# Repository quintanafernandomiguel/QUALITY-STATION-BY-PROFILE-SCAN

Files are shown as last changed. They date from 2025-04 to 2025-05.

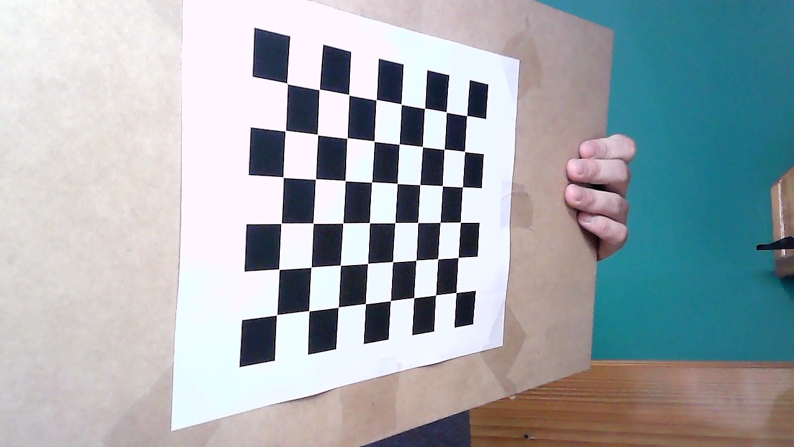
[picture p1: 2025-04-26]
Phyton/Calibracion/Imagenes/14.jpg

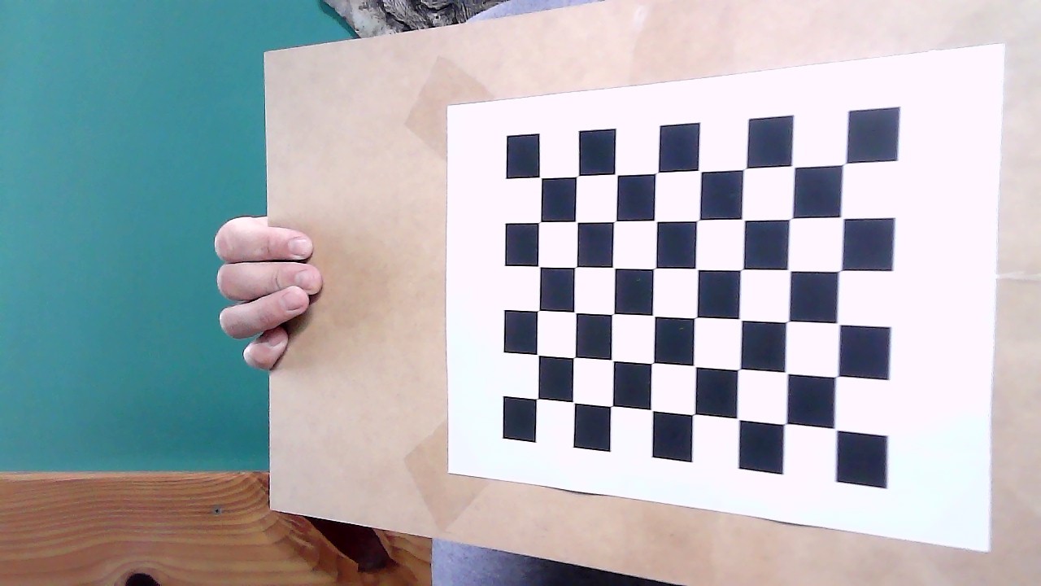
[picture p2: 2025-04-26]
Phyton/Calibracion/Imagenes/29.jpg

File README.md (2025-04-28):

# 📏 Quality Station by Profile Scan

LOGO AZUL HORIZONTAL - fondo transparente

**Universidad Nacional de Lomas de Zamora - Facultad de Ingeniería**  

**Carrera: Ingeniería Mecatrónica**

**Materia: Proyecto Final**

**Alumno: Quintana Fernando Miguel**

---

## 🎯 Motivación

En la industria moderna, donde la **velocidad, precisión y repetibilidad** son claves, el control de calidad sigue siendo una tarea muchas veces manual, lenta y propensa a errores humanos.

Este proyecto surge del interés por automatizar el control dimensional de piezas mediante **perfilometría óptica**. La propuesta plantea una alternativa accesible y didáctica a los perfilómetros industriales, utilizando una **cámara web, un láser de línea**, y técnicas de **procesamiento de imágenes con Python y OpenCV**.

---

## 🧠 Objetivo del Proyecto

Desarrollar una **estación de inspección automatizada**, capaz de:

- Escanear perfiles de piezas en tiempo real.
- Evaluar su conformidad dimensional.
- **Rechazar automáticamente** aquellas que no cumplen con las especificaciones.

---

## 🛠️ Componentes del Sistema

- **Cinta transportadora** motorizada controlada por Arduino.
- **Perfilómetro casero** (cámara web + láser de línea) para escaneo por triangulación.
- **Sensor láser** complementario para medición de distancia.
- **Controlador Arduino** que gestiona el sistema y toma decisiones.
- **Mecanismo de rechazo** activado por servoaccionamiento.
- **Interfaz gráfica en Jupyter Notebook** para visualizar estado, perfiles y resultados.

---

## ⚙️ Tecnologías Utilizadas

- **Python & OpenCV** – Procesamiento de imágenes y reconstrucción de perfiles.
- **Arduino** – Control de actuadores y adquisición de datos.
- **Jupyter Notebook** – Interfaz gráfica de usuario.
- **Diseño CAD** – Modelado mecánico de la estación.
- **Mecánica + Electrónica + Software** – Integración mecatrónica completa.

---

## 🔍 Alcance del Proyecto

Este sistema busca **automatizar el control de calidad** de piezas en una línea de producción, con un enfoque en:

- Diseño mecánico y estructura.
- Automatización con Arduino y control de motores/actuadores.
- Visión artificial aplicada, triangulación láser y escaneo.
- Desarrollo de software para análisis y visualización de resultados.

---

## 🚀 ¿Por qué es relevante?

- Aplica principios reales de la **industria 4.0**.
- Aporta una solución accesible al control dimensional automatizado.
- Ideal como proyecto didáctico, demostrativo y funcional.

---

## 📐 Esquemáticos del Sistema

PF - Quintana - Esquematico

PF - Quintana - Esquematico Comp

---

## 📸 Galería

> PF_Ensamblaje















---

## 🎥 Video de Funcionamiento

https://github.com/user-attachments/assets/4ed54965-bf86-45df-9e4f-574f1abf868d

https://github.com/user-attachments/assets/692bc483-f296-46c0-8a92-6665f114094d

https://github.com/user-attachments/assets/1b8ac1dd-ba24-4001-8854-6a46f08e3085

https://github.com/user-attachments/assets/44d58ee6-c109-4596-9ad5-b0a023ec7f68

https://github.com/user-attachments/assets/22328aee-efcb-4d32-8db1-715bef9cf719

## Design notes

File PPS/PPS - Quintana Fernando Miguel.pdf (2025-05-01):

# Informe de Práctica Profesional Supervisada

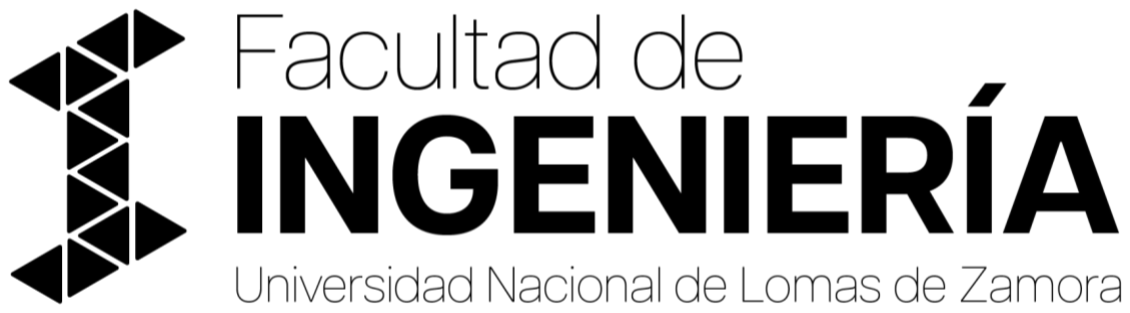
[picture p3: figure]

Institución: UNLZ-FI
Tutor Institucional: Lukaszewicz, Cristian
Tutor académico: Lukaszewicz, Cristian
Cargo institucional: Docente, materia: Proyecto final en ing. mecatrónica

Alumno: Quintana Fernando Miguel

_ _ _ _ _ _ _ _ _ _ _ _ _ _ _ _ _

Firma del Tutor Institucional

Índice

Reservado a la facultad para evaluación

Lugar donde he realizado la PPS

Desarrollé mi Práctica Profesional Supervisada en el laboratorio de Mecatrónica de la Universidad Nacional de Lomas de Zamora, Facultad de Ingeniería (UNLZ-FI), ubicado en Camino de Cintura, Avenida Juan XXIII, en la localidad de Lomas de Zamora, Provincia de Buenos Aires.

El laboratorio cuenta con diversas herramientas y tecnologías que facilitaron el desarrollo de mi proyecto, tales como fuentes de alimentación regulables, osciloscopios, multímetros y equipos de medición avanzada. Asimismo, dispone de un espacio de trabajo adecuado para el montaje, ensayo y validación de prototipos en las áreas de electrónica y mecatrónica.

Durante el transcurso de la práctica, recibí asesoramiento permanente por parte de los docentes Cristian Lukaszewicz, Ezequiel Blanca y Juan Szombach, quienes me brindaron orientación técnica y apoyo constante, permitiéndome avanzar de manera sólida en el desarrollo del proyecto.

Introducción

La automatización del control de calidad constituye uno de los pilares fundamentales de la industria moderna. El diseño de estaciones que integran técnicas de medición óptica, como la triangulación láser, junto con sistemas de visión artificial y automatización electromecánica, permite optimizar la productividad, garantizar la conformidad con los estándares de calidad y reducir significativamente los costos operativos.

En este contexto, desarrollé una estación de calidad automatizada que utiliza perfilometría basada en un láser de línea, una cámara web y programación en Python. La clasificación de las piezas inspeccionadas se gestionó mediante una placa Arduino, logrando así una solución eficiente, precisa y de bajo costo para la detección de defectos dimensionales en piezas en movimiento.

Objetivo

- Digitalizar en tiempo real el perfil superficial de las piezas inspeccionadas.
- Comparar los perfiles capturados con un modelo patrón previamente definido.
- Clasificar automáticamente las piezas como "OK" o "NO OK" mediante un sistema de rechazo controlado electrónicamente.

Principio de Triangulación Láser

La triangulación láser es una técnica de medición óptica sin contacto que permite determinar la posición tridimensional de un objeto mediante la proyección de un haz de luz y la detección de su reflexión desde un ángulo distinto.
El principio de funcionamiento se basa en que, al impactar el haz láser sobre la superficie de un objeto, el punto reflejado se registra en una posición diferente en el sensor óptico en función de la distancia al objeto. Conociendo la geometría del sistema (específicamente la distancia entre el láser y la cámara, y el ángulo de incidencia), es posible calcular la distancia precisa utilizando principios básicos de trigonometría.

Principales ventajas de la triangulación láser:

- Alta velocidad de adquisición de puntos, permitiendo capturas rápidas.
- Medición completamente sin contacto, ideal para superficies delicadas o en movimiento.
- Resolución adecuada para aplicaciones de inspección industrial y control de calidad.

La precisión del sistema depende directamente de diversos factores, tales como la calidad del haz láser, la sensibilidad y resolución del sensor óptico utilizado, así como la estabilidad mecánica de toda la configuración de medición.

Sensor CCD y su Rol en la Triangulación

Los sensores CCD (Charge Coupled Device) son componentes fundamentales en los sistemas de triangulación láser. Su funcionamiento se basa en la captura de la luz reflejada, que posteriormente es convertida en una señal eléctrica proporcional a la intensidad luminosa recibida.

Principales características del sensor CCD en aplicaciones de triangulación láser:

- Alta resolución espacial: permite capturar con precisión los detalles finos del perfil de las piezas inspeccionadas.
- Respuesta lineal: garantiza una correspondencia proporcional entre la intensidad luminosa detectada y la señal eléctrica generada.
- Sensibilidad espectral: posibilita la detección selectiva de la longitud de onda del láser mediante el uso de filtros ópticos específicos.

En los sistemas de triangulación, la cámara equipada con un sensor CCD detecta la deformación de la línea láser proyectada sobre el objeto, registrando su desplazamiento en la imagen. A partir de esta información, y aplicando los principios de triangulación geométrica, se calcula con precisión la distancia a cada punto del objeto medido.

Importancia del Punto Focal y Parámetros Ópticos

El punto focal es la región en la que el haz láser alcanza su máxima concentración de energía y su menor tamaño, generando un "spot" de alta precisión.
En los sistemas de triangulación láser, un spot reducido mejora significativamente la exactitud en la localización de los puntos de medición, mientras que una correcta focalización asegura una mayor nitidez en las imágenes capturadas por el sensor óptico.

Otros parámetros ópticos relevantes en la triangulación láser:

- Profundidad de Campo (DOF): define el rango de distancias dentro del cual el objeto permanece enfocado, siendo fundamental para capturar correctamente piezas de distintas alturas o geometrías variables.
- Campo de Visión (FOV): representa el área total observable por la cámara en cada captura, determinando el tamaño máximo del objeto que puede ser inspeccionado en una sola toma.
- Distancia de referencia (Standoff): es la distancia óptima entre el sensor y el objeto, donde se logra la mejor calidad de medición en términos de nitidez y precisión.
- Ángulo de Triangulación: es el ángulo formado entre el haz láser proyectado y la línea de visión de la cámara; afecta directamente tanto la precisión como el rango de medición disponible en el sistema.

La adecuada configuración de estos parámetros es esencial para maximizar el rendimiento de un sistema de medición basado en triangulación láser.

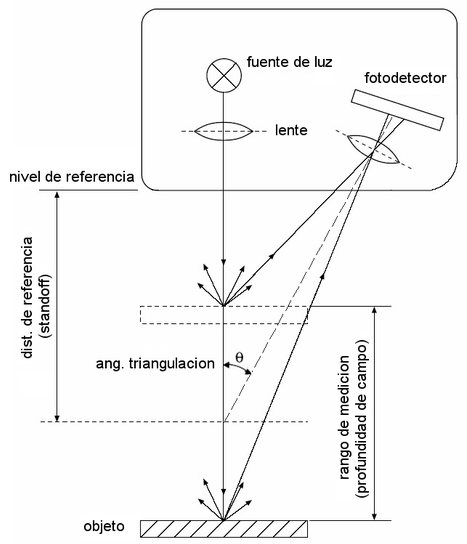
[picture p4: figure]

Descripción de la Estación de Calidad

El proyecto integra un sistema compuesto por un láser de línea, una cámara web utilizada como perfilómetro, y una cinta transportadora accionada por un motor paso a paso (PAP), todo controlado mediante una placa Arduino Nano.
La captura y el procesamiento de las imágenes del perfil de las piezas se realizan mediante programación en Python, utilizando la biblioteca OpenCV. El sistema identifica la proyección de la línea láser sobre la superficie de las piezas, detectando eventuales discrepancias al comparar el perfil capturado contra un modelo patrón predefinido. Cuando se detecta un perfil fuera de tolerancia, la placa Arduino acciona un servomotor encargado de desviar automáticamente la pieza defectuosa, asegurando la continuidad del flujo productivo sin intervención manual.
Adicionalmente, la estación cuenta con un sensor láser que mide de forma indirecta la longitud de las piezas transportadas. Esta medición se realiza mediante el conteo de los micropasos del motor paso a paso y su correlación con la distancia recorrida de la cinta transportadora.
Todo el proceso, desde la adquisición de datos hasta la clasificación de las piezas, es visualizado a través de una interfaz gráfica desarrollada en Jupyter Notebook, lo que permite un monitoreo continuo y detallado de la operación.

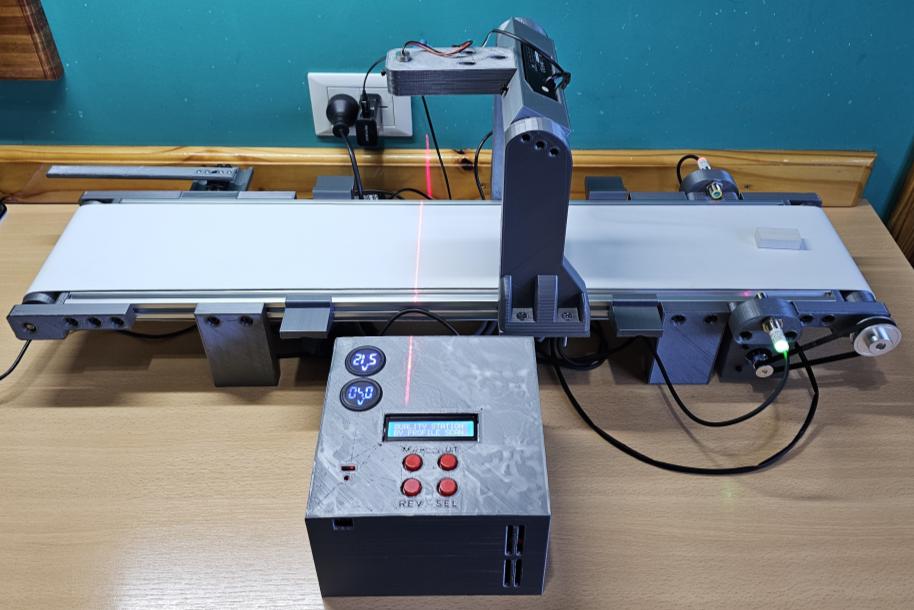
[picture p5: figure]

Metodología de Trabajo

El desarrollo de la estación de calidad automatizada se llevó a cabo siguiendo las siguientes etapas:

1. Calibración de la cámara: Realicé la obtención de la matriz intrínseca del sistema óptico y la corrección de las distorsiones de la lente, utilizando patrones de calibración y herramientas de visión computacional, asegurando así una captura precisa de las imágenes.

2. Configuración mecánica: Monté el láser de línea y la cámara web en soportes estables, estableciendo una distancia fija y un ángulo de triangulación adecuado para optimizar la detección del perfil proyectado sobre las piezas.
3. Programación en Arduino: Desarrollé el control de la cinta transportadora y del servomotor mediante una placa Arduino nano, permitiendo la gestión automática del desplazamiento de piezas y su clasificación en función del análisis de perfil.
4. Programación en Python: Implementé rutinas de captura de imágenes, procesamiento para la detección de la línea láser (utilizando filtrado de color y extracción de contornos) y algoritmos de comparación de perfiles para decidir el estado ("OK" o "NO OK") de cada pieza inspeccionada.
5. Validación mediante ensayos: Realicé pruebas experimentales con distintas piezas estándar para validar la precisión del sistema, calibrar tolerancias y ajustar los parámetros de funcionamiento, logrando optimizar la velocidad y fiabilidad del proceso de inspección.

Resultados Obtenidos

A partir de las pruebas experimentales realizadas, he obtenido los siguientes resultados:

- Detección precisa de perfiles activación automática del mecanismo de rechazo para las piezas fuera de tolerancia.
- Tiempos de inspección optimizados, logrando analizar y clasificar cada pieza en menos de 2 segundos, lo que permite un flujo continuo y eficiente en la línea de producción.
- Alta repetibilidad de los resultados en condiciones controladas de iluminación, asegurando estabilidad y confiabilidad en la detección de perfiles correctos.
- Precisión estimada de ±1 mm en la comparación de perfiles respecto al modelo patrón, suficiente para aplicaciones de inspección dimensional básica en entornos industriales o educativos.

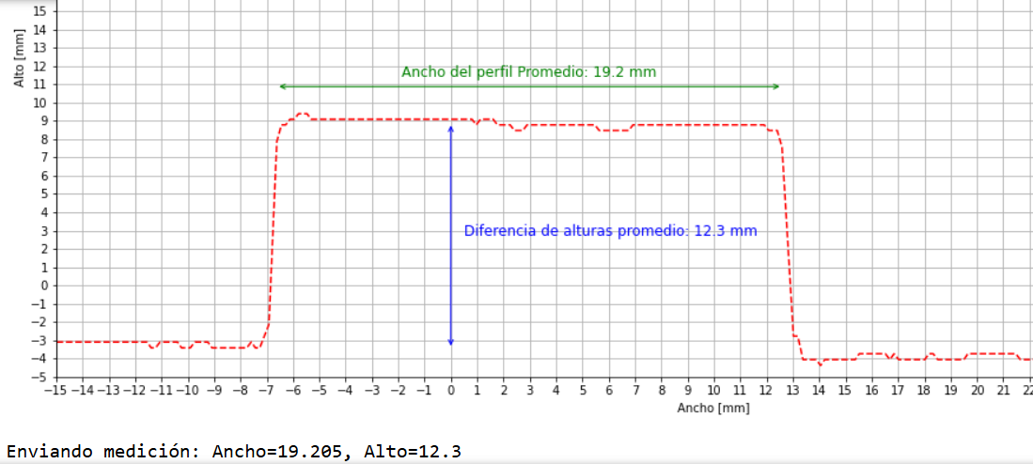
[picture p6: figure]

Ventajas y Limitaciones del Sistema

Ventajas:
- Bajo costo de materiales y desarrollo.
- Flexibilidad para modificar criterios de aceptación.
- Automatización total del proceso de inspección.

Limitaciones:
- Sensibilidad a condiciones de luz externa.
- Requiere calibración periódica.
- Dependencia de la calidad óptica de la webcam.

Costos

A continuación, muestro los diferentes elementos que componen al proyecto junto con su costo de adquisición. Esos costos extra rondan los 443,94 USD.

CANTIDAD DESCRIPCIÓN PRECIO POR UNIDAD IMPORTE $ | IMPORTE USD
1 Adaptador paralelo serie I2c $ 2.970,00 $ 2.970,00 | USD 2,27
1 Arduino Nano Atmega328 CH340 $ 5.800,00 $ 5.800,00 | USD 4,43
1 Banda R#9 130 mm x 1620 mm (ROLMEC PU-R9AM-135) $ 198.137,00 $ 198.137,00 | USD 151,25
1 Bornera enchufable hembra 3 vias P:5,08 $ 1.850,00 $ 1.850,00 | USD 1,41
2 Bornera enchufable hembra 8 vias P:5,08 $ 1.962,00 $ 3.924,00 | USD 3,00
1 Bornera enchufable macho 3 vias P:5,08 $ 1.250,00 $ 1.250,00 | USD 0,95
2 Bornera enchufable macho 8 vias P:5,08 $ 1.360,00 $ 2.720,00 | USD 2,08
4 Boton momentaneo B3f 4055 $ 480,00 $ 1.920,00 | USD 1,47
1 Cable 1 metro Nema 17 $ 2.861,00 $ 2.861,00 | USD 2,18
1 Camara REDRAGON FOBOS GW600-1 $ 59.000,00 $ 59.000,00 | USD 45,04
6 Conector terminal PCB 3x1 3,5mm $ 3.054,50 $ 18.327,00 | USD 13,99
1 Correa cerrada 280 mm GT2 6 mm 140 dientes $ 4.626,00 $ 4.626,00 | USD 3,53
1 Display LCD 16x2 HD44780 $ 7.620,00 $ 7.620,00 | USD 5,82
1 Driver TB6600 $ 14.950,00 $ 14.950,00 | USD 11,41
1 Fan cooler 3007 30 mm 5V $ 6.862,00 $ 6.862,00 | USD 5,24
2 Filamento PLA 1,75 Grilon3 1kg $ 19.569,00 $ 39.138,00 | USD 29,88
30 Inserto M3 impresión 3D $ 340,66 $ 10.219,80 | USD 7,80
1 Laser de linea 5 VDC 650 nm $ 8.825,00 $ 8.825,00 | USD 6,74
1 Modulo Asilamiento Optoacoplador Pc817 $ 5.979,00 $ 5.979,00 | USD 4,56
1 Modulo Stepdown XI4016 36V 8a $ 9.296,00 $ 9.296,00 | USD 7,10
1 Nema 17 1.8° / 42ncm $ 19.900,00 $ 19.900,00 | USD 15,19
1 PCB experimental 3x7 $ 3.343,00 $ 3.343,00 | USD 2,55
1 PCB experimental 4X6 $ 3.420,00 $ 3.420,00 | USD 2,61
2 Perfil Bosch Tslot 2020 1 metro $ 10.826,00 $ 21.652,00 | USD 16,53
1 Polea GT2 20 dientes, correa 6 mm, 5 mm aluminio $ 2.980,00 $ 2.980,00 | USD 2,27
1 Polea GT2 60 dientes, correa 6 mm, 8 mm aluminio $ 9.775,00 $ 9.775,00 | USD 7,46
4 Resitencia 10Kohm $ 45,00 $ 180,00 | USD 0,14
4 Rodamiento 608 ZZ $ 1.406,50 $ 5.626,00 | USD 4,29
1 Sensor Laser CLOWEIT J12-T20P2 $ 42.500,00 $ 42.500,00 | USD 32,44
1 Servo MG996r 10Kg Torque $ 11.600,00 $ 11.600,00 | USD 8,85
40 Tornillos allen M5 x 12 mm $ 299,05 $ 11.962,00 | USD 9,13
50 Turcas martillo perfil 2020 M5 $ 380,00 $ 19.000,00 | USD 14,50
1 Varilla templada y rectificada 8 mm x 425 mm $ 8.344,00 $ 8.344,00 | USD 6,37
2 Voltimetro digital 30 mm 4V a 100V (azul) $ 7.500,00 $ 15.000,00 | USD 11,45
TOTAL | $ 581.556,80 | USD 443,94

Conclusiones

Durante la realización de la Práctica Profesional Supervisada, he implementado con éxito una estación de control de calidad automatizada basada en el principio de triangulación láser, utilizando tecnologías accesibles como Arduino Nano, motores paso a paso, sensores ópticos y programación en Python.
Logré diseñar e integrar un sistema funcional capaz de capturar, analizar y clasificar perfiles de piezas en movimiento, replicando las funcionalidades de estaciones industriales de mayor complejidad y costo.

El proyecto integró la captura de imágenes del perfil superficial de las piezas mediante una cámara web, el procesamiento en tiempo real utilizando la biblioteca OpenCV y la comparación de los perfiles capturados contra un modelo patrón predefinido.
La detección de discrepancias activó un servomecanismo que permitió desviar automáticamente las piezas fuera de tolerancia, garantizando la continuidad del flujo de producción sin necesidad de intervención humana.

Además, incorporé un sensor láser complementario que realizó mediciones indirectas de la longitud de las piezas, sincronizando la información con el conteo de micropasos del motor paso a paso que accionó la cinta transportadora. Esta integración de hardware y software permitió realizar un doble control dimensional de forma simultánea: perfil superficial y longitud longitudinal.

Implementé una interfaz gráfica en Jupyter Notebook que permitió el monitoreo visual en tiempo real del proceso, facilitando la supervisión de perfiles, estados de piezas y estadísticas de producción.

A través de numerosas pruebas experimentales, calibré los parámetros críticos del sistema, optimizando la distancia entre el láser y la cámara, ajustando la sensibilidad del sensor óptico, y sincronizando el desplazamiento de la cinta con el control de rechazo. Conseguí tiempos de inspección inferiores a dos segundos por pieza, manteniendo una precisión adecuada para aplicaciones prototipo y de nivel preindustrial.

Esta experiencia me permitió consolidar competencias clave en metrología óptica, visión artificial, programación embebida, control de motores y diseño de sistemas automatizados.
He fortalecido mi capacidad para integrar distintas tecnologías en soluciones prácticas, enfrentando desafíos técnicos reales y desarrollando habilidades interdisciplinarias esenciales para mi futura actividad profesional.
Considero que esta práctica no solo me brindó una formación técnica avanzada, sino que también sentó las bases para futuras mejoras, como la incorporación de escaneo tridimensional completo y la aplicación de técnicas de aprendizaje automático para la optimización del proceso de clasificación.

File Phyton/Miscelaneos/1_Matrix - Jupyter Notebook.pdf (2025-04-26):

# Universidad Nacional de Lomas de Zamora

## Facultad de Ingeniería

### Proyecto FINAL - Estacion de calidad por Perfilómetria

Alumno: QUINTANA, Fernando Miguel

26/4/25, 14:56 | 1_Matrix - Jupyter Notebook
localhost:8891/notebooks/GitHub/Phyton/Programa/Codigos/1_Matrix.ipynb | 1/9

localhost:8891/notebooks/GitHub/Phyton/Programa/Codigos/1_Matrix.ipynb | 2/9

In [ ]: import numpy as np

# GeometrySpace

# Planos y rectas en el espacio euclídeo 3D

# https://www2.eii.uva.es/fund_inf/python/notebooks/Bibliotecas/03_Numpy/Numpy.html

def normaliza(v, tol=1e-6):
"""
Devuelve el vector normalizado de v.

Parameters
v : list, tuple, numpy.ndarray: numérico
Vector unidimensional
tol : float
Tolerancia que debe cumplir la norma del vector v Returns
v_norm : numpy.ndarray of floats
Vector normalizado unitario Raises
ValueError
Si la norma del vector inicial es inferior a tol Example
>>> v = (1, 1, 1)
>>> normaliza(v)
"""

norma = np.linalg.norm(v)
if norma < tol:
raise ValueError("La norma del vector es inferior a la tolerancia {}.".format(tol)) v_norm = v / norma # Al usar np.linalg.norm() v_norm es un numpy.ndarray
return v_norm

def distancia_entre_puntos(p1, p2):

localhost:8891/notebooks/GitHub/Phyton/Programa/Codigos/1_Matrix.ipynb | 3/9

"""
Calcula la distancia entre dos puntos en el espacio.

Parameters
p1, p2 : numpy.ndarray
Vectores unidimensionales
Returns
dist : numpy.float
Distancia entre los puntos p1 y p2 Example:
>>> p1 = np.array((1, 1, 1), dtype=float) >>> p2 = np.array((2, 3, 4), dtype=float)
>>> distancia_entre_puntos(p1, p2)
"""
dist = np.linalg.norm(p1 - p2) # p1-p2 no está definido para tuplas o listas return dist

def angulo(v1, v2):
"""
Calcula el ángulo en radianes entre dos vectores.

Parameters
v1, v2 : tuple, list, numpy.ndarray: numérico Vectores unidimensionales
Returns
angulo : float
Ángulo en radianes que forman los vectores Example
>>> u_x = [1, 0, 0] # Vector unitario eje X
>>> u_y = [0, 1, 0] # Vector unitario eje Y
>>> angulo(u_x, u_y)*180/np.pi # Ángulo en grados """

prod_esc = np.dot(v1, v2)
norma_v1 = np.linalg.norm(v1)
localhost:8891/notebooks/GitHub/Phyton/Programa/Codigos/1_Matrix.ipynb | 4/9

norma_v2 = np.linalg.norm(v2)

angulo = np.arccos(np.clip(prod_esc / (norma_v1 * norma_v2), -1, 1)) return angulo

def plano_tres_puntos(p1, p2, p3, tol=1e-3):
"""
Calcula el plano definido por tres puntos en el espacio.

Parameters
p1, p2, p3 : numpy.ndarray of floats
Vectores unidimensionales representando 3 puntos 3D
tol : float
Tolerancia que deben cumplir las distancias entre los puntos Returns
n, D : tuple : (numpy.ndarray of float, numpy float)
n es el vector unitario perpendicular al plano
D es el término independiente de la ecuación algebraica Ax+By+Cz+D=0 Raises
ValueError
Si la distancia entre alguno de los 3 puntos es inferior a tol Example
>>> p1 = np.array((1, 0, 0))
>>> p2 = np.array((0, 1, 0))
>>> p3 = np.array((0, 0, 1))
>>> n, D = plano_tres_puntos(p1, p2, p3) """
dist12 = distancia_entre_puntos(p1, p2)
dist13 = distancia_entre_puntos(p1, p3)
dist23 = distancia_entre_puntos(p2, p3)

if dist12 < tol or dist13 < tol or dist23 < tol:
raise ValueError("Distancia entre puntos menor que la tolerancia {}.".format(tol))

# Producto vectorial para A B C

# | i | j | k | |

# |v_12[0] v_12[1] v_12[2]|

localhost:8891/notebooks/GitHub/Phyton/Programa/Codigos/1_Matrix.ipynb | 5/9

# |v_13[0] v_13[1] v_13[2]|

v12 = p1 - p2
v13 = p1 - p3

n = normaliza(np.cross(v12, v13))

D = -np.dot(n, p1)

return n, D

def recta_dos_puntos(p1, p2, tol=1e-3): """
Parameters
p1, p2 : numpy.ndarray of floats
Vectores unidimensionales representando 2 puntos 3D
tol : float
Tolerancia que debe cumplir la distancia entre los puntos Returns
p, v : tuple: (numpy.ndarray of float, numpy.ndarray of float) p es una copia de p1, punto pasado como primer parámetro

v es el vector director unitario de la recta
Raises
ValueError
Si la distancia entre los 2 puntos es inferior a tol Example
>>> p1 = np.array((2, 2, 2))
>>> p2 = np.array((3, 3, 3))
>>> p, v = recta_dos_puntos(p1, p2)
"""
if distancia_entre_puntos(p1, p2) < tol:
raise ValueError("Distancia entre puntos menor que la tolerancia {}.".format(tol)) v = normaliza(p1 - p2)
return np.copy(p1), v
localhost:8891/notebooks/GitHub/Phyton/Programa/Codigos/1_Matrix.ipynb | 6/9

def interseccion_recta_plano(recta, plano, tol=0.0005): """
Parameters
recta : tuple : (numpy.ndarray of floats, numpy.ndarray of floats) Recta definida por la tupla punto inicial y vector director
p=p_0+l*v
plano : tuple : (numpy.ndarray of floats, float)
Plano definido por la tupla vector normal (A, B, C) y término independiente D Ax+By+Cz+D=0
tol : float
Tolerancia que deben cumplir el ángulo entre recta y plano
Returns
p : numpy.ndarray of floats
El punto de intersección
Raises
ValueError
Si el ángulo entre ambas figuras es inferior a tol en radianes Example
>>> p1 = np.array((1, 0, 0))
>>> p2 = np.array((0, 1, 0)) >>> p3 = np.array((0, 0, 1))
>>> p4 = np.array((2, 2, 2))
>>> p5 = np.array((3, 3, 3))
>>> plano = plano_tres_puntos(p1, p2, p3) >>> recta = recta_dos_puntos(p4, p5)
>>> p = interseccion_recta_plano(recta, plano) """
ang = angulo(recta[1], plano[0])

if np.abs(ang - np.pi / 2) < tol:
print(np.abs(ang - np.pi / 2))
raise ValueError("La recta y el plano son casi paralelos según tolerancia {}.".format(tol))

lamb = -(np.dot(recta[0], plano[0]) + plano[1]) / np.dot(recta[1], plano[0])

return recta[0] + lamb * recta[1]

localhost:8891/notebooks/GitHub/Phyton/Programa/Codigos/1_Matrix.ipynb | 7/9

# --------------------------------------# GeneradorMatriz

# punto focal

p_focal = np.array((-96.10, 166.45, 0))

# punto plano del laser

p_laser_1 = np.array((0, 0, 0)) p_laser_2 = np.array((0, 1, 0))
p_laser_3 = np.array((0, 0, 1))

# Datos cámara

px_wh = 0.003 # mm tamaño de alto - ancho de cada pixel
focal_dist = 7.8 # mm distancia focal de cámara
W = 732 | # Referencia pixeles verticales -> range(0, 733):
H = 1296 | # Referencia pixeles horizontales -> range(-648, 649):

# Creamos el plano del láser

plano_laser = plano_tres_puntos(p1=p_laser_1, p2=p_laser_2, p3=p_laser_3)

# Recorremos cada pixel del sensor de la cámara

mtx_ppx = []
mtx_ppy = []
mtx_ppz = []

for fpx in range(0, 733):
aux_x = []
aux_y = []
aux_z = []

# Posición de cada pixel en X e Y (varía con la fila)

pos_x = fpx * px_wh * np.cos(30 * np.pi / 180) - (100 + 360 * px_wh * np.cos(30 * np.pi / 180)) pos_y = fpx * px_wh * np.sin(30 * np.pi / 180) + (173.21 - 360 * px_wh * np.sin(30 * np.pi / 180))

# Recorremos por columna del sensor

for cpx in range(-648, 649):
if cpx == 0:
pass
else:
pos_z = cpx * px_wh
localhost:8891/notebooks/GitHub/Phyton/Programa/Codigos/1_Matrix.ipynb | 8/9

In [ ]:

# Creamos la recta del laser

px_pos = np.array((pos_x, pos_y, pos_z))
recta_haz = recta_dos_puntos(px_pos, p_focal)

# Obtenemos intersección recta-plano

intersection = interseccion_recta_plano(recta=recta_haz, plano=plano_laser)

# Guardamos la posición X,Y,Z en el espacio para ese pixel

XX = np.around(intersection, 3).tolist()[0]
YY = np.around(intersection, 3).tolist()[1]
ZZ = np.around(intersection, 3).tolist()[2]

#print(px_pos)

print("Para el pixel en el punto " + str(px_pos) + " --- > " + str(XX) + ";" + str(YY) + ";" + str(ZZ) aux_x.append(XX)
aux_y.append(YY)
aux_z.append(ZZ)

mtx_ppx.append(aux_x)
mtx_ppy.append(aux_y)
mtx_ppz.append(aux_z)

np.savetxt("mtx_x_izq.txt", mtx_ppx) np.savetxt("mtx_y_izq.txt", mtx_ppy) np.savetxt("mtx_z_izq.txt", mtx_ppz)

localhost:8891/notebooks/GitHub/Phyton/Programa/Codigos/1_Matrix.ipynb | 9/9

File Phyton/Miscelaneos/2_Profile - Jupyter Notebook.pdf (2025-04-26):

# Universidad Nacional de Lomas de Zamora

## Facultad de Ingeniería

### Proyecto FINAL - Estacion de calidad por Perfilómetria

Alumno: QUINTANA, Fernando Miguel | ¶
26/4/25, 14:56 | 2_Profile - Jupyter Notebook
localhost:8891/notebooks/GitHub/Phyton/Programa/Codigos/2_Profile.ipynb | 1/19

localhost:8891/notebooks/GitHub/Phyton/Programa/Codigos/2_Profile.ipynb | 2/19

In [ ]: # --------------------------------# Importamos librerías
import numpy as np
import cv2
import matplotlib.pyplot as plt

# Cargamos los archivos de las matrices de posición X, Y y Z mtx_xi = np.loadtxt("mtx_x_izq.txt") # Matriz pos. pixeles en X

mtx_yi = np.loadtxt("mtx_y_izq.txt") # Matriz pos. pixeles en Y
mtx_zi = np.loadtxt("mtx_z_izq.txt") # Matriz pos. pixeles en Z

# Creamos las variables auxiliares a utilizar en la ejecución del programa

scale_factor_x = 1 | # Escalado en X
scale_factor_y = 2.3 | # Escalado en Y
scale_factor_z = 2.3 | # Escalado en Z

# Creamos los offset en X, Y y Z para mover el grafico. offset_x = 0

offset_y = -18
offset_z = 0

# Creamos la función para filtrado de "ROJO" mediante HSV def HSV_FILTRO(image):

# Duplicamos la imagen

result = image.copy()
# Convertimos la imagen a espacio de color HSV

hsv_image = cv2.cvtColor(image, cv2.COLOR_BGR2HSV)
# Definimos los límites inferiores y superiores del color rojo en HSV lower_red = np.array([0, 50, 50])

upper_red = np.array([10, 255, 255])
# Creamos la máscara para el color rojo

mask1 = cv2.inRange(hsv_image, lower_red, upper_red)
# Definimos un rango adicional para el color rojo debido a su disposición en el espacio de color HSV lower_red = np.array([170, 50, 50])

upper_red = np.array([180, 255, 255])
# Creamos otra máscara para el color rojo

mask2 = cv2.inRange(hsv_image, lower_red, upper_red)
# Combinamos ambas máscaras para obtener una única máscara para el rojo

mask = cv2.bitwise_or(mask1, mask2)
# Aplicamos la máscara a la imagen original para obtener solo los píxeles rojos

localhost:8891/notebooks/GitHub/Phyton/Programa/Codigos/2_Profile.ipynb | 3/19

result = cv2.bitwise_and(result, result, mask=mask) # Convertimos la imagen resultante a escala de grises img_gris = cv2.cvtColor(result, cv2.COLOR_BGR2GRAY) # Retornamos la imagen filtrada
return img_gris

# Creamos la función para calibración de imagen

def CALIBRAR(imagen, h, w):
# PROPIEDADES INTRÍNSECAS DE CÁMARA

# Matriz intrínseca de Cámara

M_int = np.array([[1.38106997e03, 0.00000000e00, 6.87317037e02], [0.00000000e00, 1.38209804e03, 3.82421364e02], [0.00000000e00, 0.00000000e00, 1.00000000e00]])

# Matríz de Distorsión

D = np.array([8.30863128e-02, 1.57413825e00, 4.52467136e-04, 5.90615097e-03, -7.07611874e00])

# Matriz Transformación de Cámara - Pixel

newcameramtx, roi = cv2.getOptimalNewCameraMatrix(M_int, D, (w, h), 1, (w, h), centerPrincipalPoint=False)

# Matriz Imagen calibrada

dst = cv2.undistort(imagen, M_int, D, None, newcameramtx)

# Se ajusta tamaño de imagen

x, y, w, h = roi
dst = dst[y : y + h, x : x + w]

# Retorna imagen calibrada

return dst

# Creamos la función para procesar la imagen

def PROCESAR(image):
# Inicializamos las variables a utilizar

perfil_puntos = [] # Lista de puntos del perfil de la pieza
pos_pix2 = [] # Lista de cada pixel a encontrar en las matrices de referencia

# Obtenemos el tamaño de la imagen recibida

h, w = image.shape[:2]

# Procesamos la imagen -> calibramos y filtramos "ROJO" image = CALIBRAR(image, h, w)

image = HSV_FILTRO(image)
localhost:8891/notebooks/GitHub/Phyton/Programa/Codigos/2_Profile.ipynb | 4/19

# Aplicamos un tresh para poner los pixeles en 1 o 0 según los valores límites fijados image = cv2.threshold(image, 15, 255, cv2.THRESH_BINARY)[1]

# Mostramos imagen con umbral aplicado

cv2.imshow("Imagen", image)
cv2.waitKey(0)

# Recorremos todas las columnas de la imagen, para asegurarnos obtener una linea lo más fina posible a la curv img_columnas = len(image[0]) # Obtenemos la cantidad de columnas que tiene la imagen

for col in range(0, img_columnas):
vpx = np.where(image[:, col] != 0) # Aquellos pixeles con "1" son los pixeles que queremos ubicar

# Si para dicha columna tenemos pixeles en "1", entonces lo guardamos en la lista

if len(vpx[0]) > 0:
# Ubicamos el pixel más centrado de la linea para ajustar lo más posible.

if len(vpx[0]) % 2 == 0:
pos_pix2.append([vpx[0][int(len(vpx[0]) / 2)], col])
else:
pos_pix2.append([vpx[0][int(round(len(vpx[0]) / 2, 0))], col])

# Para cada posición encontrada, se obtienen los valores de X, Y y Z en el espacio según sistema de referencia for px in pos_pix2:

# Posición en X * escalado

x = (mtx_xi[px[0], px[1]] * scale_factor_x) + offset_x
# Posición en Y * escalado

y = (mtx_yi[px[0], px[1]] * scale_factor_y) + offset_y
# Posición en Z * escalado

z = (mtx_zi[px[0], px[1]] * scale_factor_z) + offset_z

# Guardamos en la lista la posición en X, Y y Z de cada pixel perfil_puntos.append([x, y, z])

# Retornamos la lista de puntos

return np.array(perfil_puntos)

# Leemos imagen del directorio

img = cv2.imread("D:/Trabajo Final (Perfilometro)/Programa/ImgsPerfilometro/WIN_20240208_21_51_56_Pro.jpg") #img = cv2.imread("D:/Trabajo Final (Perfilometro)/Programa/ImgsPerfilometro/WIN_20240218_16_16_26_Pro.jpg")

# Mostramos imagen original

localhost:8891/notebooks/GitHub/Phyton/Programa/Codigos/2_Profile.ipynb | 5/19

cv2.imshow("Original", img) cv2.waitKey(0)

# Procesamos imagen y obtenemos el perfil

puntos_perfil = PROCESAR(img)

# Graficamos los puntos obtenidos

plt.figure(figsize=(20, 10)) # Ajustamos el tamaño del gráfico plt.plot(puntos_perfil[:, 2], puntos_perfil[:, 1], linestyle="dashed", color="red") plt.xticks(range(-15, 35, 1)) # Ajustamos los intervalos de los números en los ejes x y y plt.yticks(range(-5, 30, 1))
plt.grid()
plt.xlabel("Ancho [mm]")
plt.ylabel("Alto [mm]")
plt.xlim(-15, 35)
plt.ylim(-5, 30)
plt.show()
localhost:8891/notebooks/GitHub/Phyton/Programa/Codigos/2_Profile.ipynb | 6/19

### Calculo de altura del perfil

localhost:8891/notebooks/GitHub/Phyton/Programa/Codigos/2_Profile.ipynb | 7/19

In [ ]: | # Calculamos la altura puntos_encima_2mm = puntos_perfil[puntos_perfil[:, 1] > 2] # Filtramos los puntos por encima de 2 mm en el eje Y puntos_debajo_2mm = puntos_perfil[puntos_perfil[:, 1] < 2] # Filtramos los puntos por debajo de 2 mm en el eje Y
| # Ordenamos los puntos filtrados por su valor en el eje X puntos_encima_2mm_sorted = np.sort(puntos_encima_2mm, axis=0) puntos_debajo_2mm_sorted = np.sort(puntos_debajo_2mm, axis=0)
| # Calculamos los índices que representan el 10% de los valores más bajos y altos para los puntos por encima de 2 m n_encima = len(puntos_encima_2mm_sorted) low_index_encima = int(n_encima * 0.1) high_index_encima = int(n_encima * 0.9)
| # Seleccionamos solo los valores dentro del rango del 10% al 90% para los puntos por encima de 2 mm puntos_80_percent_encima = puntos_encima_2mm_sorted[low_index_encima:high_index_encima]
| # Calculamos el promedio de los valores seleccionados para los puntos por encima de 2 mm altura_promedio_80_percent_encima = np.mean(puntos_80_percent_encima[:, 1])
| # Realizamos el mismo proceso para los puntos por debajo de 2 mm n_debajo = len(puntos_debajo_2mm_sorted) low_index_debajo = int(n_debajo * 0.1) high_index_debajo = int(n_debajo * 0.9) puntos_80_percent_debajo = puntos_debajo_2mm_sorted[low_index_debajo:high_index_debajo] altura_promedio_80_percent_debajo = np.mean(puntos_80_percent_debajo[:, 1])
| # Calculamos la diferencia entre los promedios de los puntos por encima y por debajo de 2 mm diferencia_altura_promedio = round(altura_promedio_80_percent_encima - altura_promedio_80_percent_debajo, 1)
| # Mostramos los resultados print("Altura promedio del perfil (80% de los valores por encima de 2 mm):", round(altura_promedio_80_percent_enci print("Altura promedio de la base (80% de los valores por debajo de 2 mm):", round(altura_promedio_80_percent_deba print("Diferencia de alturas promedio:", diferencia_altura_promedio, "mm")
localhost:8891/notebooks/GitHub/Phyton/Programa/Codigos/2_Profile.ipynb | 8/19

### Calculo del ancho del perfil

In [ ]: | # Encontrar el inicio y el final del perfil inicio_perfil = None fin_perfil = None for i in range(len(puntos_perfil)): # Si el valor de Y es mayor a 2 mm, encontramos el inicio del perfil if puntos_perfil[i, 1] > 2: inicio_perfil = i break
| for i in range(len(puntos_perfil) - 1, -1, -1): # Si el valor de Y es mayor a 2 mm, encontramos el final del perfil if puntos_perfil[i, 1] > 2: fin_perfil = i break
| # Calcular el ancho del perfil if inicio_perfil is not None and fin_perfil is not None: ancho_perfil = puntos_perfil[inicio_perfil, 2] - puntos_perfil[fin_perfil, 2] print("Ancho del perfil:", ancho_perfil, "mm") else: print("No se encontraron puntos para calcular el ancho del perfil.")
localhost:8891/notebooks/GitHub/Phyton/Programa/Codigos/2_Profile.ipynb | 9/19

### Graficamos el perfil con los datos obtenidos

In [ ]: | # Graficar el perfil con datos: plt.figure(figsize=(20, 10)) # Ajustamos el tamaño del gráfico plt.plot(puntos_perfil[:, 2], puntos_perfil[:, 1], linestyle="dashed", color="red")
| # Dibujar flecha para el ancho plt.annotate('', xy=(puntos_perfil[fin_perfil, 2], altura_promedio_80_percent_encima + 2), xytext=(puntos_perfil[inicio_perfil, 2], altura_promedio_80_percent_encima + 2), arrowprops=dict(arrowstyle='<->', color='green')) plt.text((puntos_perfil[inicio_perfil, 2] + puntos_perfil[fin_perfil, 2]) / 2, altura_promedio_80_percent_encima + 2.5, 'Ancho del perfil Promedio: {} mm'.format(round(ancho_perfil, 1) color='green', fontsize=12, ha='center')
| # Dibujar flecha para la altura promedio plt.annotate('', xy=(0, altura_promedio_80_percent_debajo), xytext=(0, altura_promedio_80_percent_encima), arrowprops=dict(arrowstyle='<->', color='blue')) plt.text(0.5, (altura_promedio_80_percent_encima + altura_promedio_80_percent_debajo) / 2, f'Diferencia de alturas promedio: {diferencia_altura_promedio} mm', color='blue', fontsize=12, ha='left')
| plt.xticks(range(-15, 35, 1)) # Ajustamos los intervalos de los números en los ejes x y y plt.yticks(range(-5, 30, 1)) plt.grid() plt.xlabel("Ancho [mm]") plt.ylabel("Alto [mm]") plt.xlim(-15, 35) plt.ylim(-5, 30) plt.show()
localhost:8891/notebooks/GitHub/Phyton/Programa/Codigos/2_Profile.ipynb | 10/19

### INTERFACE ARDUINO

localhost:8891/notebooks/GitHub/Phyton/Programa/Codigos/2_Profile.ipynb | 11/19

In [ ]: import serial
import time
import numpy as np
import cv2
import matplotlib.pyplot as plt

# Configurar puerto serie (Cambia 'COM4' si es necesario)

ser = serial.Serial('COM4', 115200, timeout=1) # Windows: 'COM4', Linux/Mac: '/dev/ttyUSB0' time.sleep(2) # Esperar a que el puerto se estabilice

print("Esperando comandos de Arduino...")

# Importamos librerías

# Cargamos los archivos de las matrices de posición X, Y y Z

mtx_xi = np.loadtxt("mtx_x_izq.txt") # Matriz pos. pixeles en X
mtx_yi = np.loadtxt("mtx_y_izq.txt") # Matriz pos. pixeles en Y
mtx_zi = np.loadtxt("mtx_z_izq.txt") # Matriz pos. pixeles en Z

# Creamos las variables auxiliares a utilizar en la ejecución del programa

scale_factor_x = 1 | # Escalado en X
scale_factor_y = 2.3 | # Escalado en Y
scale_factor_z = 2.3 | # Escalado en Z

# Creamos los offset en X, Y y Z para mover el grafico.

offset_x = 0
offset_y = -18
offset_z = 0

# Creamos la función para filtrado de "ROJO" mediante HSV

def HSV_FILTRO(image):
# Duplicamos la imagen

result = image.copy()
localhost:8891/notebooks/GitHub/Phyton/Programa/Codigos/2_Profile.ipynb | 12/19

# Convertimos la imagen a espacio de color HSV

hsv_image = cv2.cvtColor(image, cv2.COLOR_BGR2HSV)
# Definimos los límites inferiores y superiores del color rojo en HSV lower_red = np.array([0, 50, 50])

upper_red = np.array([10, 255, 255])
# Creamos la máscara para el color rojo

mask1 = cv2.inRange(hsv_image, lower_red, upper_red)
# Definimos un rango adicional para el color rojo debido a su disposición en el espacio de color HSV lower_red = np.array([170, 50, 50])

upper_red = np.array([180, 255, 255])
# Creamos otra máscara para el color rojo

mask2 = cv2.inRange(hsv_image, lower_red, upper_red)
# Combinamos ambas máscaras para obtener una única máscara para el rojo

mask = cv2.bitwise_or(mask1, mask2)
# Aplicamos la máscara a la imagen original para obtener solo los píxeles rojos result = cv2.bitwise_and(result, result, mask=mask)

# Convertimos la imagen resultante a escala de grises

img_gris = cv2.cvtColor(result, cv2.COLOR_BGR2GRAY)
# Retornamos la imagen filtrada

return img_gris

# Creamos la función para calibración de imagen

def CALIBRAR(imagen, h, w):
# PROPIEDADES INTRÍNSECAS DE CÁMARA

# Matriz intrínseca de Cámara

M_int = np.array([[1.38106997e03, 0.00000000e00, 6.87317037e02], [0.00000000e00, 1.38209804e03, 3.82421364e02], [0.00000000e00, 0.00000000e00, 1.00000000e00]])

# Matríz de Distorsión

D = np.array([8.30863128e-02, 1.57413825e00, 4.52467136e-04, 5.90615097e-03, -7.07611874e00])

# Matriz Transformación de Cámara - Pixel

newcameramtx, roi = cv2.getOptimalNewCameraMatrix(M_int, D, (w, h), 1, (w, h), centerPrincipalPoint=False)

# Matriz Imagen calibrada

dst = cv2.undistort(imagen, M_int, D, None, newcameramtx)

# Se ajusta tamaño de imagen

x, y, w, h = roi
localhost:8891/notebooks/GitHub/Phyton/Programa/Codigos/2_Profile.ipynb | 13/19

dst = dst[y : y + h, x : x + w]

# Retorna imagen calibrada

return dst

# Creamos la función para procesar la imagen

def PROCESAR(image):
# Inicializamos las variables a utilizar

perfil_puntos = [] # Lista de puntos del perfil de la pieza
pos_pix2 = [] # Lista de cada pixel a encontrar en las matrices de referencia

# Obtenemos el tamaño de la imagen recibida

h, w = image.shape[:2]

# Procesamos la imagen -> calibramos y filtramos "ROJO"

image = CALIBRAR(image, h, w)
image = HSV_FILTRO(image)

# Aplicamos un tresh para poner los pixeles en 1 o 0 según los valores límites fijados

image = cv2.threshold(image, 15, 255, cv2.THRESH_BINARY)[1]

# Recorremos todas las columnas de la imagen, para asegurarnos obtener una linea lo más fina posible a la curv img_columnas = len(image[0]) # Obtenemos la cantidad de columnas que tiene la imagen

for col in range(0, img_columnas):
vpx = np.where(image[:, col] != 0) # Aquellos pixeles con "1" son los pixeles que queremos ubicar

# Si para dicha columna tenemos pixeles en "1", entonces lo guardamos en la lista

if len(vpx[0]) > 0:
# Ubicamos el pixel más centrado de la linea para ajustar lo más posible.

if len(vpx[0]) % 2 == 0:
pos_pix2.append([vpx[0][int(len(vpx[0]) / 2)], col])
else:
pos_pix2.append([vpx[0][int(round(len(vpx[0]) / 2, 0))], col])

# Para cada posición encontrada, se obtienen los valores de X, Y y Z en el espacio según sistema de referencia for px in pos_pix2:

# Posición en X * escalado

x = (mtx_xi[px[0], px[1]] * scale_factor_x) + offset_x
# Posición en Y * escalado

localhost:8891/notebooks/GitHub/Phyton/Programa/Codigos/2_Profile.ipynb | 14/19

y = (mtx_yi[px[0], px[1]] * scale_factor_y) + offset_y
# Posición en Z * escalado

z = (mtx_zi[px[0], px[1]] * scale_factor_z) + offset_z

# Guardamos en la lista la posición en X, Y y Z de cada pixel perfil_puntos.append([x, y, z])

# Retornamos la lista de puntos

return np.array(perfil_puntos)

# Esperar hasta que Arduino envíe "MEDIR"

while True:
if ser.in_waiting > 0:
comando = ser.readline().decode('utf-8').strip() print(f"Recibido comando: {comando}")

if comando == "MEDIR":
try:

# Capturar imagen desde la cámara

cap = cv2.VideoCapture(0) # Usar cámara por defecto (ajustar índice si es necesario) cap.set(cv2.CAP_PROP_FRAME_WIDTH, 1280)
cap.set(cv2.CAP_PROP_FRAME_HEIGHT, 720)

if not cap.isOpened():
print("Error: No se pudo abrir la cámara.") ser.write("0 0\r\n".encode('utf-8')) continue

ret, frame = cap.read()
cap.release()

if not ret:
print("Error: No se pudo capturar la imagen.")
ser.write("0 0\r\n".encode('utf-8'))
continue

# Guardar imagen capturada como 'profile.jpg', sobrescribiendo si ya existe

ruta_imagen = "D:/UNLZ/4 - Proyecto final (1C2025)/Phyton/Programa/ImgsPerfilometro/profile.jpg" cv2.imwrite(ruta_imagen, frame)
localhost:8891/notebooks/GitHub/Phyton/Programa/Codigos/2_Profile.ipynb | 15/19

# Cargar la imagen recién guardada para procesarla img = cv2.imread(ruta_imagen)

# Procesa imagen SOLO cuando Arduino lo solicite

#img = cv2.imread("D:/Trabajo Final (Perfilometro)/Programa/ImgsPerfilometro/WIN_20240208_21_51_56 #img = cv2.imread("D:/Trabajo Final (Perfilometro)/Programa/ImgsPerfilometro/WIN_20240218_16_16_26

if img is None:
print("Error: No se pudo cargar la imagen.")
ser.write("0 0\r\n".encode('utf-8'))
continue

# Procesamos imagen y obtenemos el perfil puntos_perfil = PROCESAR(img)

# CALCULO ALTURA PERFIL

puntos_encima_2mm = puntos_perfil[puntos_perfil[:, 1] > 2] # Filtramos los puntos por encima de 2 puntos_debajo_2mm = puntos_perfil[puntos_perfil[:, 1] < 2] # Filtramos los puntos por debajo de 2

# Ordenamos los puntos filtrados por su valor en el eje X

puntos_encima_2mm_sorted = np.sort(puntos_encima_2mm, axis=0)
puntos_debajo_2mm_sorted = np.sort(puntos_debajo_2mm, axis=0)

# Calculamos los índices que representan el 10% de los valores más bajos y altos para los puntos p n_encima = len(puntos_encima_2mm_sorted)

low_index_encima = int(n_encima * 0.1)
high_index_encima = int(n_encima * 0.9)

# Seleccionamos solo los valores dentro del rango del 10% al 90% para los puntos por encima de 2 m puntos_80_percent_encima = puntos_encima_2mm_sorted[low_index_encima:high_index_encima]

# Calculamos el promedio de los valores seleccionados para los puntos por encima de 2 mm altura_promedio_80_percent_encima = np.mean(puntos_80_percent_encima[:, 1])

# Realizamos el mismo proceso para los puntos por debajo de 2 mm

n_debajo = len(puntos_debajo_2mm_sorted)
low_index_debajo = int(n_debajo * 0.1)
high_index_debajo = int(n_debajo * 0.9)
localhost:8891/notebooks/GitHub/Phyton/Programa/Codigos/2_Profile.ipynb | 16/19

puntos_80_percent_debajo = puntos_debajo_2mm_sorted[low_index_debajo:high_index_debajo] altura_promedio_80_percent_debajo = np.mean(puntos_80_percent_debajo[:, 1])

# Calculamos la diferencia entre los promedios de los puntos por encima y por debajo de 2 mm diferencia_altura_promedio = round(altura_promedio_80_percent_encima - altura_promedio_80_percent_

# CALCULO ANCHO PERFIL

# Encontrar el inicio y el final del perfil inicio_perfil = None

fin_perfil = None
for i in range(len(puntos_perfil)):
# Si el valor de Y es mayor a 2 mm, encontramos el inicio del perfil if puntos_perfil[i, 1] > 2:

inicio_perfil = i
break

for i in range(len(puntos_perfil) - 1, -1, -1):
# Si el valor de Y es mayor a 2 mm, encontramos el final del perfil if puntos_perfil[i, 1] > 2:

fin_perfil = i
break

# Calcular el ancho del perfil

if inicio_perfil is not None and fin_perfil is not None:
ancho_perfil = puntos_perfil[inicio_perfil, 2] - puntos_perfil[fin_perfil, 2]

# GRAFICO EL PERFIL

plt.figure(figsize=(20, 10)) # Ajustamos el tamaño del gráfico plt.plot(puntos_perfil[:, 2], puntos_perfil[:, 1], linestyle="dashed", color="red")

# Dibujar flecha para el ancho

plt.annotate('', xy=(puntos_perfil[fin_perfil, 2], altura_promedio_80_percent_encima + 2), xytext=(puntos_perfil[inicio_perfil, 2], altura_promedio_80_percent_encima + 2), arrowprops=dict(arrowstyle='<->', color='green')) plt.text((puntos_perfil[inicio_perfil, 2] + puntos_perfil[fin_perfil, 2]) / 2, altura_promedio_80_percent_encima + 2.5, 'Ancho del perfil Promedio: {} mm'.format(round( color='green', fontsize=12, ha='center')
localhost:8891/notebooks/GitHub/Phyton/Programa/Codigos/2_Profile.ipynb | 17/19

In [ ]:

In [ ]:

# Dibujar flecha para la altura promedio

plt.annotate('', xy=(0, altura_promedio_80_percent_debajo),
xytext=(0, altura_promedio_80_percent_encima),
arrowprops=dict(arrowstyle='<->', color='blue'))
plt.text(0.5, (altura_promedio_80_percent_encima + altura_promedio_80_percent_debajo) / 2, f'Diferencia de alturas promedio: {diferencia_altura_promedio} mm', color='blue', fontsiz

plt.xticks(range(-15, 35, 1)) # Ajustamos los intervalos de los números en los ejes x y y plt.yticks(range(-5, 30, 1))
plt.grid()
plt.xlabel("Ancho [mm]")
plt.ylabel("Alto [mm]")
plt.xlim(-15, 35)
plt.ylim(-5, 30)
plt.show()

# ENVIO VALORES A ARDUNIO

mensaje = f"{ancho_perfil} {diferencia_altura_promedio}\r\n" ser.write(mensaje.encode('utf-8'))
print(f"Enviando medición: Ancho={ancho_perfil}, Alto={diferencia_altura_promedio}")

except Exception as e:
print(f"Error al calcular perfil: {e}")
ser.write("0 0\r\n".encode('utf-8'))
localhost:8891/notebooks/GitHub/Phyton/Programa/Codigos/2_Profile.ipynb | 18/19

localhost:8891/notebooks/GitHub/Phyton/Programa/Codigos/2_Profile.ipynb | 19/19

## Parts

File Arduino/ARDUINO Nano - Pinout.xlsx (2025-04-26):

D2 | Pulsador 1
D3 | Pulsador 2
D4 | Pulsador 3
D5 | Pulsador 4
D6 | Sensor Laser
D7 | Driver TB6600 (+DIR)
D8 | Driver TB6600 (+PUL)
D9 | Servo MG996R PWM
D10 | Spare
D11 | Spare
D12 | Spare
A1 | Spare
A2 | Spare
A3 | Spare
A4 | LCD 16x2 (SDA)
A5 | LCD 16x2 (SCL)
A6 | Spare
A7 | Spare

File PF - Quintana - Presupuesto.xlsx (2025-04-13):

 | PROYECTO FINAL
 | Quality station by profile scan
 | CANTIDAD | DESCRIPCIÓN | PRECIO POR UNIDAD | IMPORTE $ | IMPORTE USD
CLIENTE | 1 | Adaptador paralelo serie I2c | $2970.00 | $2970.00 | USD 2.27
Quintana Fernando Miguel | 1 | Arduino Nano Atmega328 CH340 | $5800.00 | $5800.00 | USD 4.43
N.º DE PRESUPUESTO | 1 | Banda R#9 130 mm x 1620 mm (ROLMEC PU-R9AM-135) | $198137.00 | $198137.00 | USD 151.25
UNLZ-1C2025 | 1 | Bornera enchufable hembra 3 vias P:5,08 | $1850.00 | $1850.00 | USD 1.41
FECHA | 2 | Bornera enchufable hembra 8 vias P:5,08 | $1962.00 | $3924.00 | USD 3.00
2025-04-02 | 1 | Bornera enchufable macho 3 vias P:5,08 | $1250.00 | $1250.00 | USD 0.95
Dólar MEP | 2 | Bornera enchufable macho 8 vias P:5,08 | $1360.00 | $2720.00 | USD 2.08
1310 | 4 | Boton momentaneo B3f 4055 | $480.00 | $1920.00 | USD 1.47
 | 1 | Cable 1 metro Nema 17 | $2861.00 | $2861.00 | USD 2.18
 | 1 | Camara REDRAGON FOBOS GW600-1 | $59000.00 | $59000.00 | USD 45.04
 | 6 | Conector terminal PCB 3x1 3,5mm | $3054.50 | $18327.00 | USD 13.99
 | 1 | Correa cerrada 280 mm GT2 6 mm 140 dientes | $4626.00 | $4626.00 | USD 3.53
 | 1 | Display LCD 16x2 HD44780 | $7620.00 | $7620.00 | USD 5.82
 | 1 | Driver TB6600 | $14950.00 | $14950.00 | USD 11.41
 | 1 | Fan cooler 3007 30 mm 5V | $6862.00 | $6862.00 | USD 5.24
 | 2 | Filamento PLA 1,75 Grilon3 1kg | $19569.00 | $39138.00 | USD 29.88
 | 30 | Inserto M3 impresión 3D | $340.66 | $10219.80 | USD 7.80
 | 1 | Laser de linea 5 VDC 650 nm | $8825.00 | $8825.00 | USD 6.74
 | 1 | Modulo Asilamiento Optoacoplador Pc817 | $5979.00 | $5979.00 | USD 4.56
 | 1 | Modulo Stepdown XI4016 36V 8a | $9296.00 | $9296.00 | USD 7.10
 | 1 | Nema 17 1.8° / 42ncm | $19900.00 | $19900.00 | USD 15.19
 | 1 | PCB experimental 3x7 | $3343.00 | $3343.00 | USD 2.55
 | 1 | PCB experimental 4X6 | $3420.00 | $3420.00 | USD 2.61
 | 2 | Perfil Bosch Tslot 2020 1 metro | $10826.00 | $21652.00 | USD 16.53
 | 1 | Polea GT2 20 dientes, correa 6 mm, 5 mm aluminio | $2980.00 | $2980.00 | USD 2.27
 | 1 | Polea GT2 60 dientes, correa 6 mm, 8 mm aluminio | $9775.00 | $9775.00 | USD 7.46
 | 4 | Resitencia 10Kohm | $45.00 | $180.00 | USD 0.14
 | 4 | Rodamiento 608 ZZ | $1406.50 | $5626.00 | USD 4.29
 | 1 | Sensor Laser CLOWEIT J12-T20P2 | $42500.00 | $42500.00 | USD 32.44
 | 1 | Servo MG996r 10Kg Torque | $11600.00 | $11600.00 | USD 8.85
 | 40 | Tornillos allen M5 x 12 mm | $299.05 | $11962.00 | USD 9.13
 | 50 | Turcas martillo perfil 2020 M5 | $380.00 | $19000.00 | USD 14.50
 | 1 | Varilla templada y rectificada 8 mm x 425 mm | $8344.00 | $8344.00 | USD 6.37
 | 2 | Voltimetro digital 30 mm 4V a 100V (azul) | $7500.00 | $15000.00 | USD 11.45
 |  |  | TOTAL | $581556.80 | USD 443.94

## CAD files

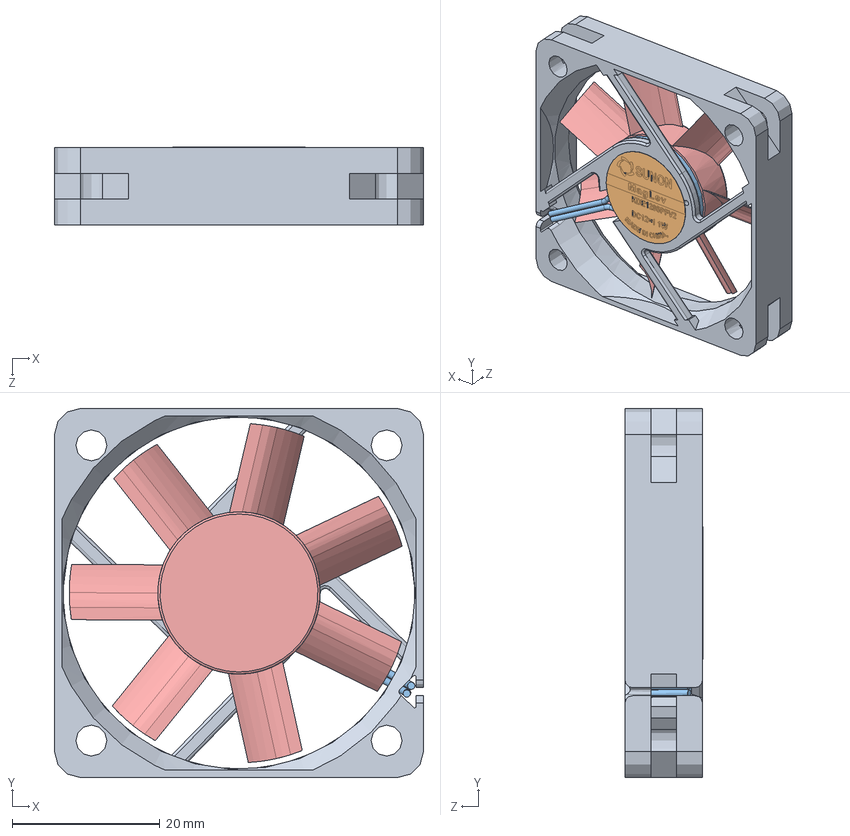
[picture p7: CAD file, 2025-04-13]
Panel de control/Cooler 50X50X10.5/Cooler 50x50x10.5 detailed SBORKA.SLDASM
50.0 x 50.0 x 10.6 mm
Cooler 50x50x10.5 body
Sticker SUNON
Cooler pcb
Cooler Motor
Cooler Blades

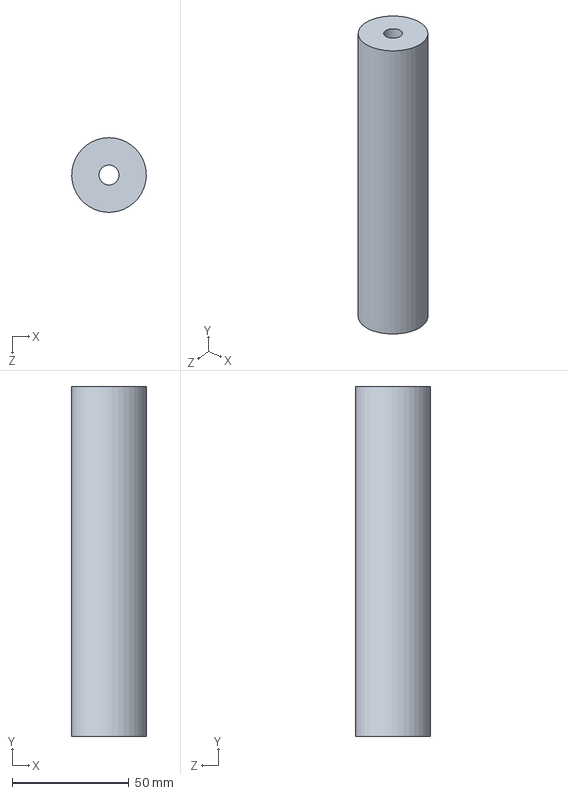
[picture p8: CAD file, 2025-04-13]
Cinta transportadora/PF_Rodillo_32.SLDPRT
32.0 x 150.0 x 32.0 mm

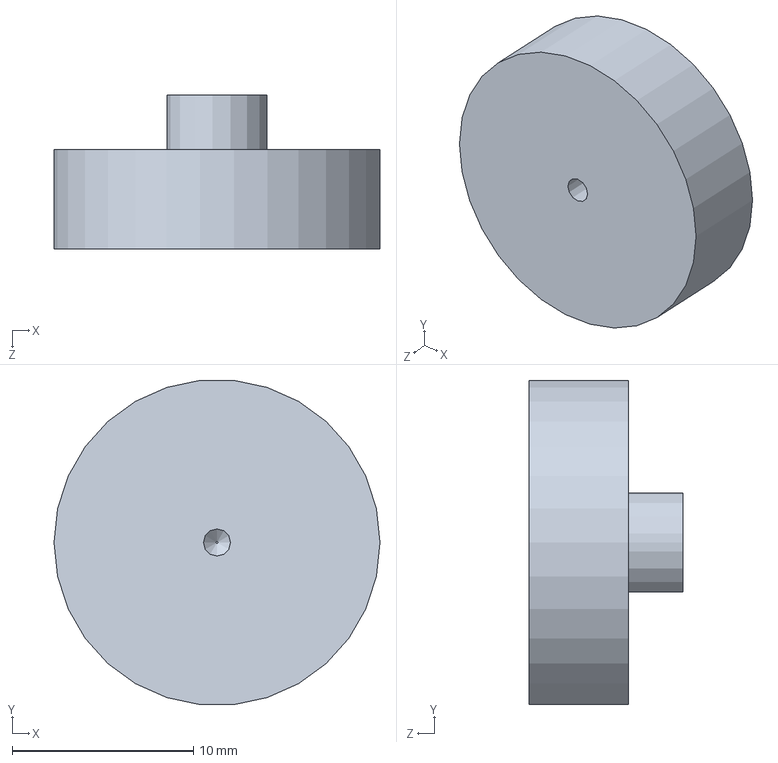
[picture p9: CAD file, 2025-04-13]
Panel de control/Cooler 50X50X10.5/Cooler Motor.SLDPRT
18.0 x 17.9 x 8.50 mm

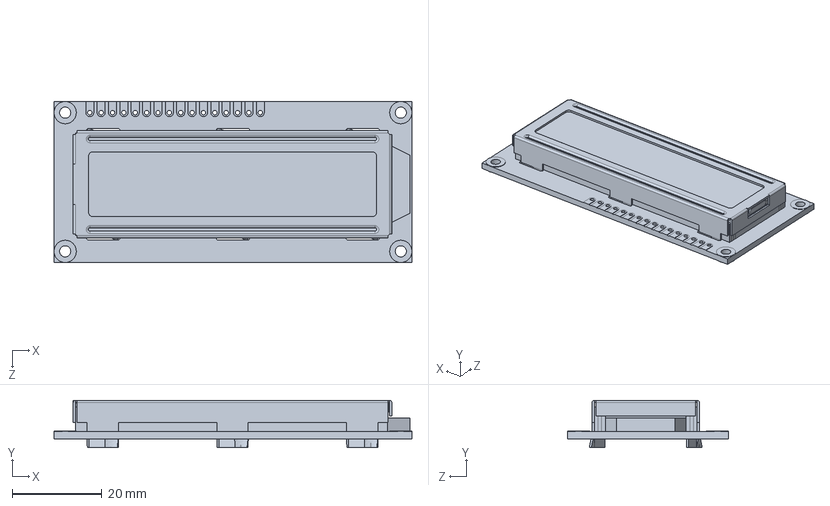
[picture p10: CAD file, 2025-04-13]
Panel de control/LCD 16x2.SLDPRT
80.0 x 10.6 x 36.0 mm

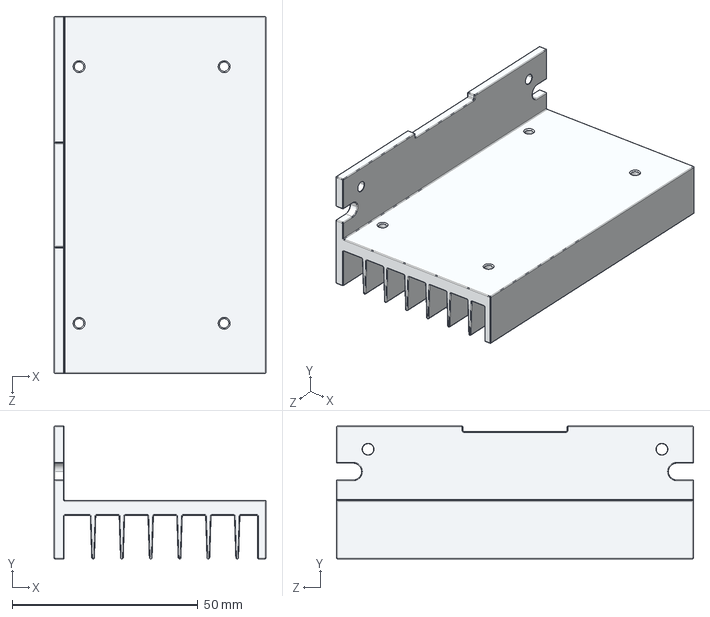
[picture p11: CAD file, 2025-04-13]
Panel de control/TB6600/TB6600 Sink.STEP
57.0 x 35.8 x 96.0 mm

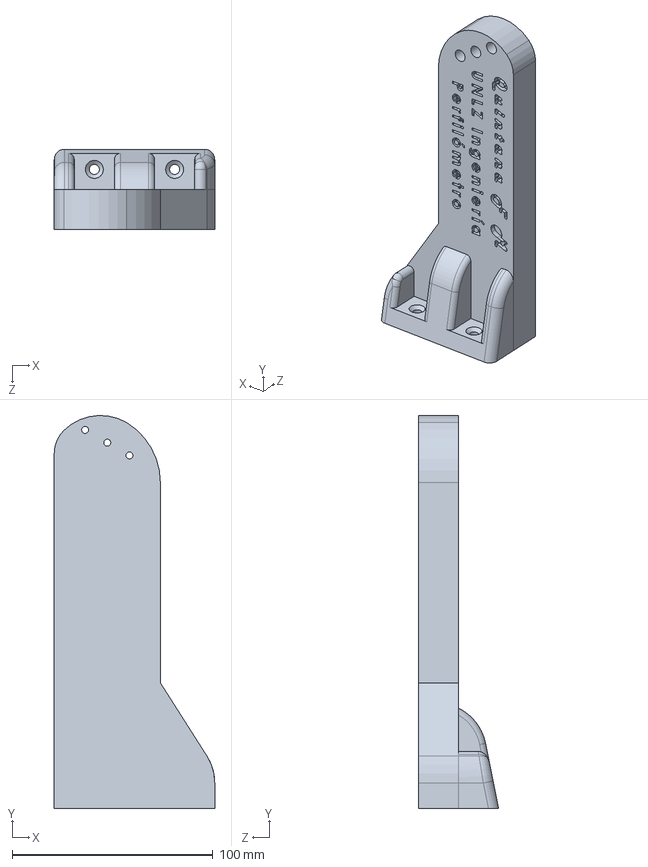
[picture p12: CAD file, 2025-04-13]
Perfilometro/Perfilometro - Columna R.SLDPRT
80.0 x 195.8 x 40.0 mm

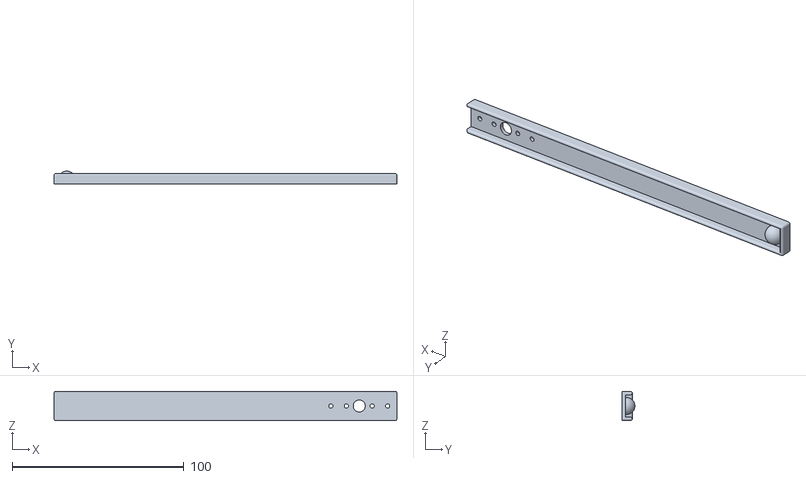
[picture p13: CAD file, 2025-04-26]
STL/PF_Derivador.STL
200.0 x 7.50 x 17.0

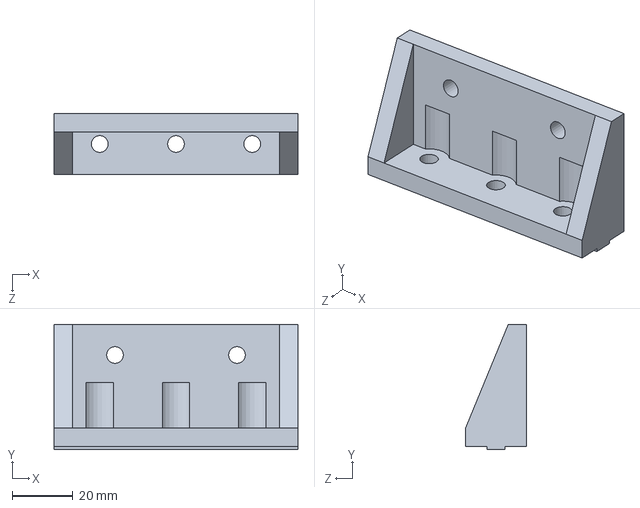
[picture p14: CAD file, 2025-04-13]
Cinta transportadora/PF_Soporte_Perfilometro.SLDPRT
80.0 x 41.0 x 20.0 mm

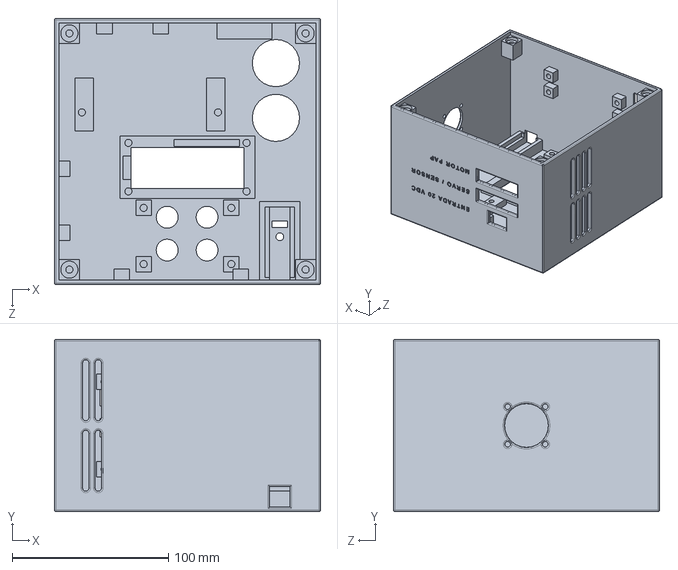
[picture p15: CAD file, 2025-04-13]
Panel de control/Case.SLDPRT
170.0 x 110.0 x 170.0 mm

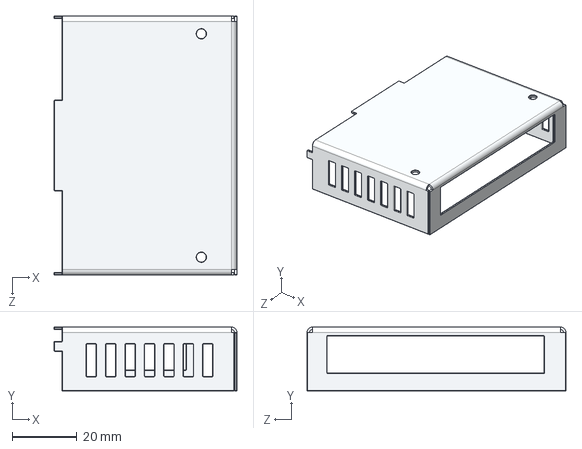
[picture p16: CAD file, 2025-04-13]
Panel de control/TB6600/TB6600 Cover.STEP
56.5 x 19.8 x 80.0 mm

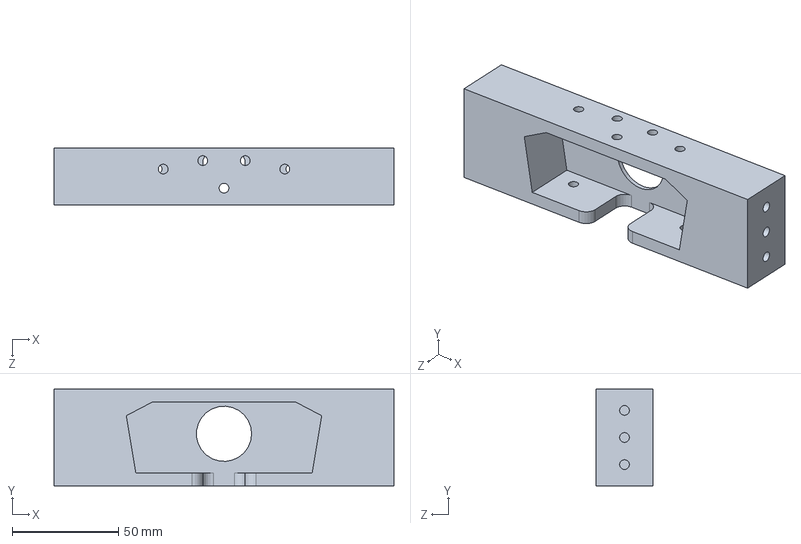
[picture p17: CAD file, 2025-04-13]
Perfilometro/Perfilometro - Soporte Camara.SLDPRT
160.0 x 45.5 x 27.0 mm

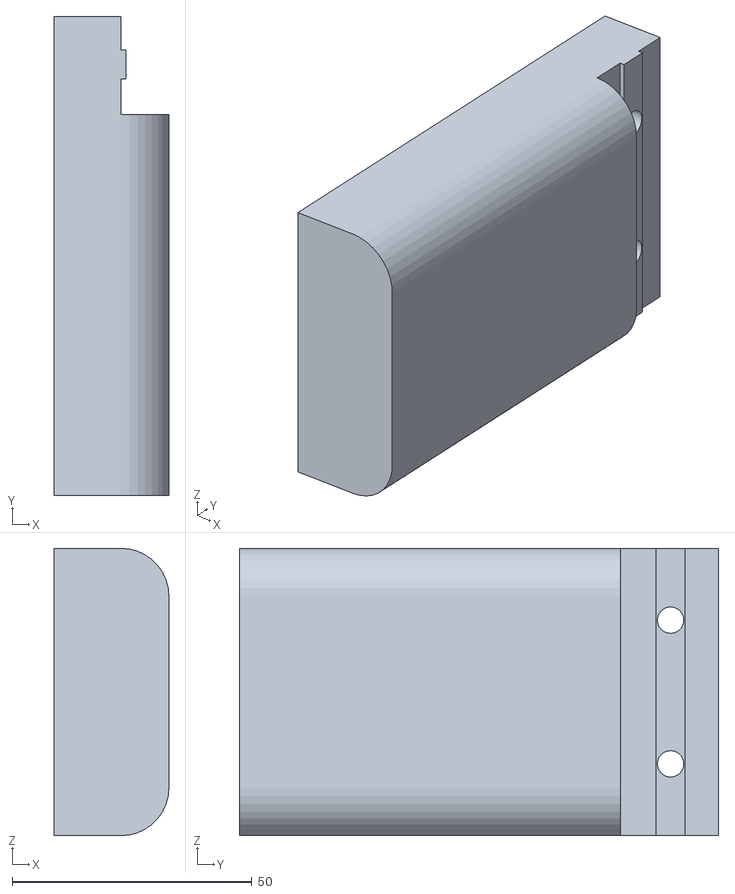
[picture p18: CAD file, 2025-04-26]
STL/PF_Pie.STL
24.0 x 100.0 x 60.0

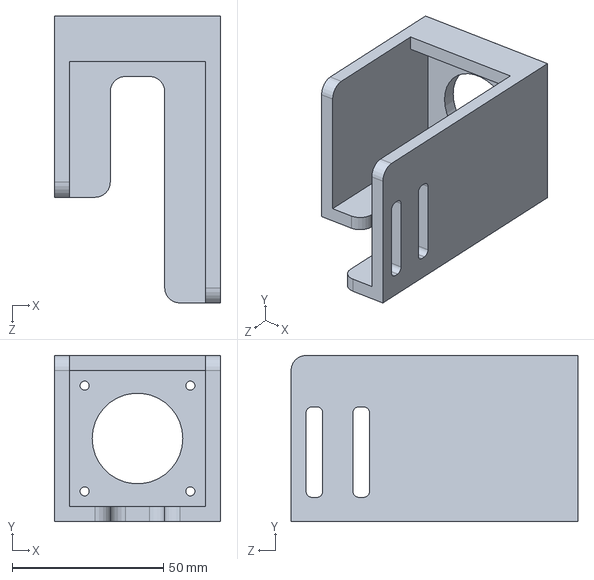
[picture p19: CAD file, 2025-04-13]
Cinta transportadora/PF_Soporte_Sensor.SLDPRT
55.0 x 55.0 x 95.0 mm

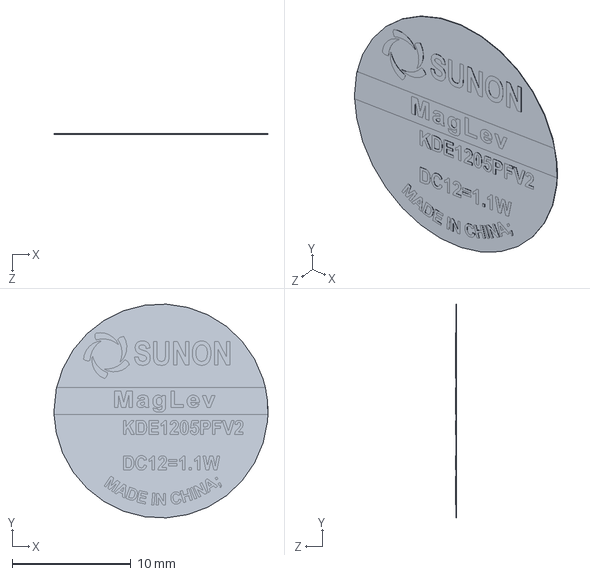
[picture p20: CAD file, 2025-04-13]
Panel de control/Cooler 50X50X10.5/Sticker SUNON.SLDPRT
18.0 x 18.0 x 0.07 mm

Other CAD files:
Panel de control/Tapa.SLDPRT
Panel de control/TB6600/Plug 200mil.STEP
Perfilometro/Perfilometro - Soporte Laser.SLDPRT
STL/PF_Soporte_BlackBox.STL
Cinta transportadora/AD_DM7-0N1A_TACH SENSOR.SLDPRT
Cinta transportadora/M12 SS NUT.SLDPRT
Cinta transportadora/PF_Caja_Bloqueo_Luz.SLDPRT
Cinta transportadora/PF_Cinta.SLDPRT
Cinta transportadora/PF_Derivador.SLDPRT
Cinta transportadora/PF_Eje_175.SLDPRT
Cinta transportadora/PF_Eje_200.SLDPRT
Cinta transportadora/PF_Perfil_BOSCH_2020.SLDPRT
Cinta transportadora/PF_Perfil_BOSCH_2020_250.SLDPRT
Cinta transportadora/PF_Pie_A.SLDPRT
Cinta transportadora/PF_Pie_CajaBlack.SLDPRT
Cinta transportadora/PF_Polea_GT2_20D_5.SLDPRT
Cinta transportadora/PF_Polea_GT2_40D_5.SLDPRT
Cinta transportadora/PF_Polea_GT2_40D_8.SLDPRT
Cinta transportadora/PF_Polea_GT2_60D_8.SLDPRT
Cinta transportadora/PF_Sensor_O1D100.SLDPRT
Cinta transportadora/PF_Separador.SLDPRT
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

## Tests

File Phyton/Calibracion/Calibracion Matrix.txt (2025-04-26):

total error: 0.04057939955400003
Camera matrix : 

[[1.38106997e+03 0.00000000e+00 6.87317037e+02]
 [0.00000000e+00 1.38209804e+03 3.82421364e+02]
 [0.00000000e+00 0.00000000e+00 1.00000000e+00]]
dist : 

[[ 8.30863128e-02  1.57413825e+00  4.52467136e-04  5.90615097e-03
  -7.07611874e+00]]
rvecs : 

(array([[-0.0416594 ],
       [-0.05076577],
       [-1.56568963]]), array([[ 0.04625338],
       [-0.7670991 ],
       [ 1.52736709]]), array([[-0.26207996],
       [-0.66156024],
       [ 1.51229107]]), array([[-0.29925268],
       [-0.54651194],
       [ 1.5183757 ]]), array([[-0.4589761 ],
       [-0.66005512],
       [ 1.52058477]]), array([[-0.67029974],
       [-0.80299551],
       [ 1.46463665]]), array([[-0.80883498],
       [-0.90449201],
       [ 1.40600899]]), array([[-0.46951772],
       [-0.98745953],
       [ 1.57932307]]), array([[-0.26656798],
       [-0.95917057],
       [ 1.60708358]]), array([[-0.17703571],
       [-0.68461087],
       [ 1.55029957]]), array([[-0.21117803],
       [-0.61996615],
       [ 1.61622236]]), array([[-0.16447035],
       [-0.10062261],
       [ 1.57363269]]), array([[ 0.14255201],
       [ 0.45178679],
       [-1.5401225 ]]), array([[ 0.07420924],
       [ 0.49529596],
       [-1.53018898]]), array([[-0.01088277],
       [ 0.61862076],
       [ 1.5705237 ]]), array([[0.03451664],
       [0.91614609],
       [1.56068654]]), array([[0.15810593],
       [1.00326634],
       [1.58411317]]), array([[0.5220887 ],
       [0.47012761],
       [1.46592455]]), array([[0.61119353],
       [0.41579388],
       [1.40449186]]), array([[0.44489766],
       [0.41253625],
       [1.46615349]]), array([[0.45433114],
       [0.28276543],
       [1.53804553]]), array([[0.4994996 ],
       [0.45372655],
       [1.54677541]]), array([[-0.17143249],
       [ 0.0625492 ],
       [-1.51953457]]), array([[0.63818676],
       [0.62305536],
       [1.52177487]]), array([[0.69600311],
       [0.69232712],
       [1.49845351]]), array([[0.81319272],
       [0.82487006],
       [1.47060223]]), array([[0.78824054],
       [0.83964357],
       [1.47285068]]), array([[0.88468413],
       [0.92606426],
       [1.42984539]]), array([[-0.34961921],
       [ 1.07036396],
       [-1.46564889]]), array([[ 0.08489608],
       [ 0.85861898],
       [-1.49763299]]), array([[ 0.36050493],
       [ 0.69865425],
       [-1.43883596]]), array([[ 0.4060665 ],
       [ 0.67293166],
       [-1.51762043]]), array([[-0.16310255],
       [-0.84803246],
       [ 1.67062749]]), array([[-0.15120514],
       [ 0.22033784],
       [-1.52115985]]), array([[-0.19740968],
       [-0.74496165],
       [ 1.50565952]]), array([[-0.22043627],
       [-0.7387244 ],
       [ 1.58233769]]), array([[-0.21882212],
       [-0.81084135],
       [ 1.60013926]]), array([[ 0.63505256],
       [ 0.53638124],
       [-1.43595596]]), array([[ 0.51660328],
       [ 0.37638199],
       [-1.4717315 ]]), array([[ 0.19303269],
       [-0.38128039],
       [ 1.52122193]]), array([[ 8.45855167e-05],
       [-1.67656800e-01],
       [ 1.57507534e+00]]), array([[-0.22917975],
       [ 0.06545163],
       [ 1.55184024]]), array([[-0.45306337],
       [-0.65867032],
       [-1.51515809]]), array([[-0.87997611],
       [ 0.68378959],
       [ 1.32706585]]), array([[-0.05587807],
       [ 0.34620914],
       [-1.54424047]]), array([[-1.02102542],
       [ 0.14984886],
       [ 1.19924975]]), array([[-0.07774246],
       [ 0.9327717 ],
       [ 1.66375531]]), array([[0.22888451],
       [0.60173719],
       [1.57806043]]), array([[0.38555971],
       [0.8173298 ],
       [1.56556563]]), array([[0.61961966],
       [0.93331491],
       [1.51970697]]), array([[-0.65218162],
       [-0.67100818],
       [ 1.51338055]]), array([[-0.30809321],
       [-0.33988498],
       [ 1.57198028]]), array([[-0.09088654],
       [-0.50347025],
       [ 1.5912111 ]]), array([[-0.72468529],
       [ 0.05843587],
       [ 1.39346276]]), array([[-1.01199333],
       [-0.37887935],
       [ 1.22083839]]), array([[ 0.43619587],
       [-0.04124564],
       [ 1.53614232]]), array([[0.41126343],
       [0.8953389 ],
       [1.54821566]]), array([[0.68020452],
       [0.37761367],
       [1.33986024]]), array([[-0.45754336],
       [ 0.68025571],
       [-1.44310198]]), array([[-0.36097427],
       [ 0.58751915],
       [-1.46547769]]), array([[-0.23923316],
       [ 0.45140434],
       [-1.46595619]]), array([[-0.13568235],
       [-0.34122953],
       [ 1.58847473]]), array([[ 0.48620971],
       [-0.39204139],
       [ 1.4902497 ]]), array([[ 0.52499168],
       [-0.6460363 ],
       [ 1.47329304]]), array([[ 0.31789018],
       [-0.82539397],
       [ 1.51211798]]))
tvecs : 

(array([[-5.37205603],
       [ 2.38287951],
       [27.01724906]]), array([[ 2.01885688],
       [-2.76152547],
       [25.97160145]]), array([[-0.20355103],
       [-3.07730303],
       [25.96315441]]), array([[-0.97955946],
       [-3.22636656],
       [26.17411523]]), array([[ 2.74037485],
       [-3.14686462],
       [26.4912166 ]]), array([[ 1.13539351],
       [-3.41137387],
       [24.12028427]]), array([[ 0.20088076],
       [-3.21725776],
       [23.14357823]]), array([[ 1.54216621],
       [-3.07756458],
       [22.8532476 ]]), array([[ 2.13722381],
       [-2.99322405],
       [23.19886022]]), array([[ 3.78233368],
       [-3.31262391],
       [23.66558801]]), array([[ 5.47037652],
       [-2.92242766],
       [24.51382253]]), array([[ 1.33849827],
       [-2.95640388],
       [27.60533419]]), array([[-1.31590807],
       [ 1.93643864],
       [27.07822315]]), array([[-3.89825352],
       [ 1.75121424],
       [27.51041927]]), array([[ 3.2123883 ],
       [-2.69698818],
       [23.41253377]]), array([[ 4.87982588],
       [-2.48903018],
       [23.02896383]]), array([[ 5.5250428 ],
       [-2.49495287],
       [22.50106447]]), array([[ 5.30337594],
       [-2.69977423],
       [21.66969941]]), array([[ 5.35609768],
       [-1.72379275],
       [21.26003039]]), array([[ 5.18906032],
       [-3.14419277],
       [21.67979485]]), array([[ 4.81869688],
       [-3.01747868],
       [21.59236338]]), array([[ 5.33659995],
       [-2.75840221],
       [21.40986862]]), array([[-4.46593987],
       [ 1.42837043],
       [28.05010871]]), array([[ 5.43451008],
       [-2.18799512],
       [20.09665334]]), array([[ 1.82310271],
       [-2.31310752],
       [18.97152141]]), array([[ 1.66099985],
       [-2.17103398],
       [18.27470086]]), array([[ 1.87368769],
       [-3.29399997],
       [18.1196213 ]]), array([[ 1.89108475],
       [-3.1321065 ],
       [17.94502523]]), array([[-2.8468381 ],
       [ 0.18808123],
       [25.14560468]]), array([[-6.95953758],
       [-0.15686626],
       [23.41417633]]), array([[-4.03350285],
       [ 0.28009011],
       [21.5339801 ]]), array([[-4.28200456],
       [ 1.14318466],
       [21.20615768]]), array([[ 2.72173975],
       [-2.82657438],
       [20.63027047]]), array([[-3.80360321],
       [ 1.56636753],
       [28.6163737 ]]), array([[ 1.12116286],
       [-3.36596141],
       [20.5554715 ]]), array([[ 1.46489154],
       [-3.39772264],
       [21.22305378]]), array([[ 3.26840785],
       [-3.14106369],
       [21.31342315]]), array([[-4.17025657],
       [ 1.18158896],
       [20.06711856]]), array([[-3.98669358],
       [ 1.3421995 ],
       [19.99979083]]), array([[ 2.92587503],
       [-2.52863398],
       [18.57424488]]), array([[ 3.44712259],
       [-2.68160199],
       [19.96840264]]), array([[ 3.36060443],
       [-2.50037438],
       [20.71262828]]), array([[-3.50113057],
       [ 1.45469846],
       [17.51364239]]), array([[ 3.15253953],
       [-0.91807549],
       [21.92174415]]), array([[-3.4704096 ],
       [ 1.59248359],
       [28.92372097]]), array([[ 0.94027202],
       [-2.30572457],
       [21.92324615]]), array([[ 4.83206615],
       [-1.99984297],
       [21.90623075]]), array([[ 4.9844911 ],
       [-2.74602437],
       [21.26957131]]), array([[ 3.19898878],
       [-3.2146816 ],
       [20.05046793]]), array([[ 1.89035543],
       [-2.6070366 ],
       [20.31285633]]), array([[ 3.4086634 ],
       [-2.6577698 ],
       [22.58372359]]), array([[ 3.91552155],
       [-2.85325924],
       [22.3954312 ]]), array([[ 4.72369008],
       [-2.98333963],
       [22.00839514]]), array([[ 3.1867703 ],
       [-2.6824981 ],
       [23.91015834]]), array([[ 2.26520972],
       [-2.71728578],
       [23.47996287]]), array([[ 3.40513175],
       [-2.91212303],
       [25.96984092]]), array([[ 4.18355418],
       [-2.67937762],
       [24.89147719]]), array([[ 4.19212832],
       [-3.08756164],
       [24.87768889]]), array([[-0.54567821],
       [ 1.2169412 ],
       [29.33016185]]), array([[-1.56140712],
       [ 1.69421907],
       [28.27306361]]), array([[-2.75445991],
       [ 1.51016346],
       [26.56431252]]), array([[ 1.47406294],
       [-3.10117614],
       [22.58347102]]), array([[ 2.86567399],
       [-2.46262389],
       [25.33193915]]), array([[ 2.51288482],
       [-2.32736085],
       [25.03245283]]), array([[ 2.5583181 ],
       [-2.12023605],
       [25.26517708]]))

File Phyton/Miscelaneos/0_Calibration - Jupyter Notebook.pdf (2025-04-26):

# Universidad Nacional de Lomas de Zamora

## Facultad de Ingeniería

### Proyecto FINAL - Estacion de calidad por Perfilómetria

Alumno: QUINTANA, Fernando Miguel

26/4/25, 14:54 | 0_Calibration - Jupyter Notebook
localhost:8891/notebooks/GitHub/Phyton/Calibracion/0_Calibration.ipynb | 1/5

localhost:8891/notebooks/GitHub/Phyton/Calibracion/0_Calibration.ipynb | 2/5

In [ ]: # Importamos Librerías import cv2
import numpy as np
import glob

# Definimos las dimensiones de la tabla de ajedrez de prueba

CHECKERBOARD = (6, 8) # 6 puntos verticales y 8 puntos horizontales

# Se establece criterio máximo de iteración y error

criteria = (cv2.TERM_CRITERIA_EPS + cv2.TERM_CRITERIA_MAX_ITER, 30, 0.0001)

# Vector para almacenar cada vector 3D en la proyección de la imagen objpoints = []

# Vector para almacenar cada vector 2D en la proyección de la imagen imgpoints = []

# Se definen las coordenadas del espacio para los puntos en 3D

objp = np.zeros((1, CHECKERBOARD[0] * CHECKERBOARD[1], 3), np.float32)
objp[0, :, :2] = np.mgrid[0:CHECKERBOARD[0], 0:CHECKERBOARD[1]].T.reshape(-1, 2) prev_img_shape = None

# Carpeta donde se encuentran las fotos de calibración

images = glob.glob("Imagenes/*.jpg")
cont = 0

# Se itera cada imagen

for fname in images:
# Se lee imagen

img = cv2.imread(fname)

# Se convierte a escalas de grises

gray = cv2.cvtColor(img, cv2.COLOR_BGR2GRAY)

# Se identifican las esquinas de la tabla de ajedrez # Si las encuentra, devuelve True

ret, corners = cv2.findChessboardCorners(
gray,
CHECKERBOARD,
cv2.CALIB_CB_ADAPTIVE_THRESH
+ cv2.CALIB_CB_FAST_CHECK
localhost:8891/notebooks/GitHub/Phyton/Calibracion/0_Calibration.ipynb | 3/5

+ cv2.CALIB_CB_NORMALIZE_IMAGE, )

if ret:
# Agrega los puntos al vector

objpoints.append(objp)

# Refina los puntos para los vectores 2D

corners2 = cv2.cornerSubPix(gray, corners, (11, 11), (-1, -1), criteria)

# Se agregan a los puntos de imagen

imgpoints.append(corners2)

# Dibuja las esquinas sobre la imagen

img = cv2.drawChessboardCorners(img, CHECKERBOARD, corners2, ret)

# Guarda las imágenes en la carpeta nuevamente

# cv2.imwrite(str("Fotos/") + str(cont) + ".jpg", img)

cont += 1

# Muestra las imágenes

cv2.imshow("img", img)
cv2.waitKey(10)

# Cierra todas las ventanas cv2.destroyAllWindows()

# Obtiene el tamaño de imagen

h, w = img.shape[:2]

# Calibra la cámara pasando como parámetros, los diferentes vectores 3D y 2D de las imágenes procesadas ret, mtx, dist, rvecs, tvecs = cv2.calibrateCamera(

objpoints, imgpoints, gray.shape[::-1], None, None
)

# Calcula el error

mean_error = 0
for i in range(len(objpoints)):
imgpoints2, _ = cv2.projectPoints(objpoints[i], rvecs[i], tvecs[i], mtx, dist) error = cv2.norm(imgpoints[i], imgpoints2, cv2.NORM_L2) / len(imgpoints2) mean_error += error
localhost:8891/notebooks/GitHub/Phyton/Calibracion/0_Calibration.ipynb | 4/5

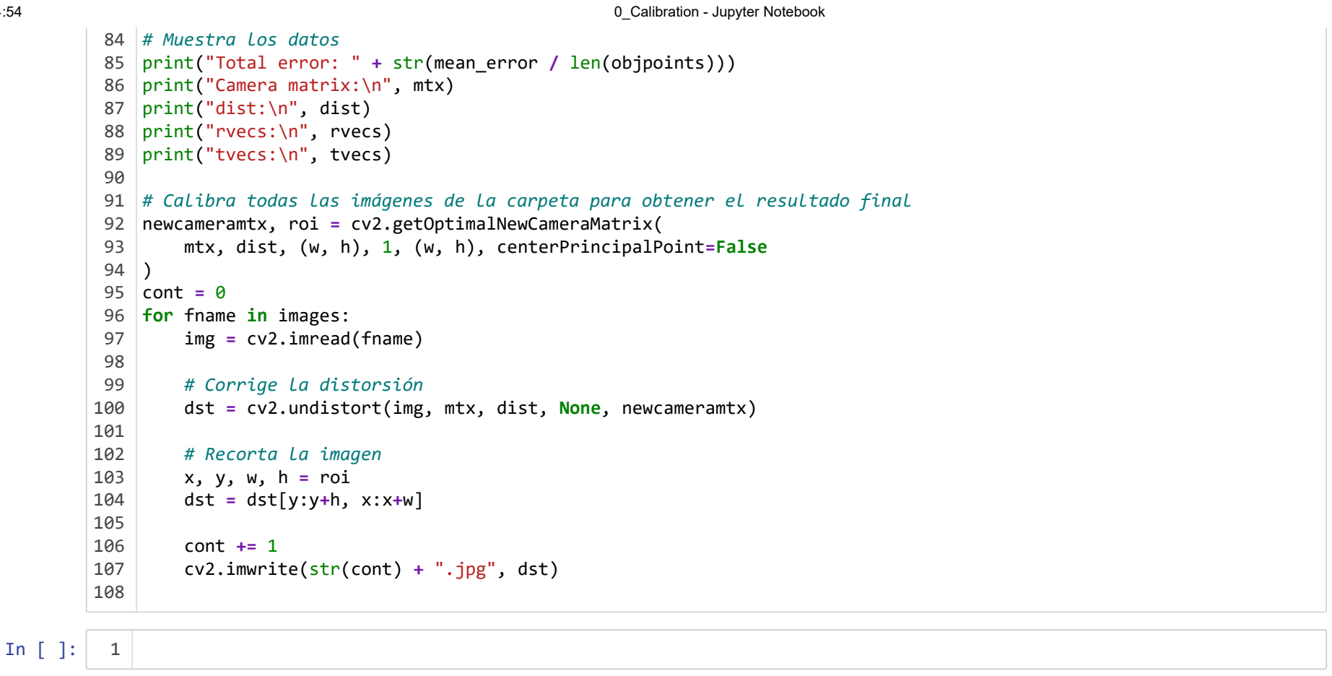
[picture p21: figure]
# Muestra los datos; print("Camera matrix:\n", mtx) print("dist:\n", dist) print("rvecs:\n", rvecs) print("tvecs:\n", tvecs); newcameramtx, roi = cv2.getOptimalNewCameraMatrix(; ) cont = 0 for fname in images: img = cv2.imread(fname); # Corrige la distorsión; # Recorta la imagen x, y, w, h = roi dst = dst[y:y+h, x:x+w]; cont += 1 cv2.imwrite(str(cont) + ".jpg", dst)

print("Total error: " + str(mean_error / len(objpoints)))

# Calibra todas las imágenes de la carpeta para obtener el resultado final

mtx, dist, (w, h), 1, (w, h), centerPrincipalPoint=False

dst = cv2.undistort(img, mtx, dist, None, newcameramtx)

localhost:8891/notebooks/GitHub/Phyton/Calibracion/0_Calibration.ipynb | 5/5

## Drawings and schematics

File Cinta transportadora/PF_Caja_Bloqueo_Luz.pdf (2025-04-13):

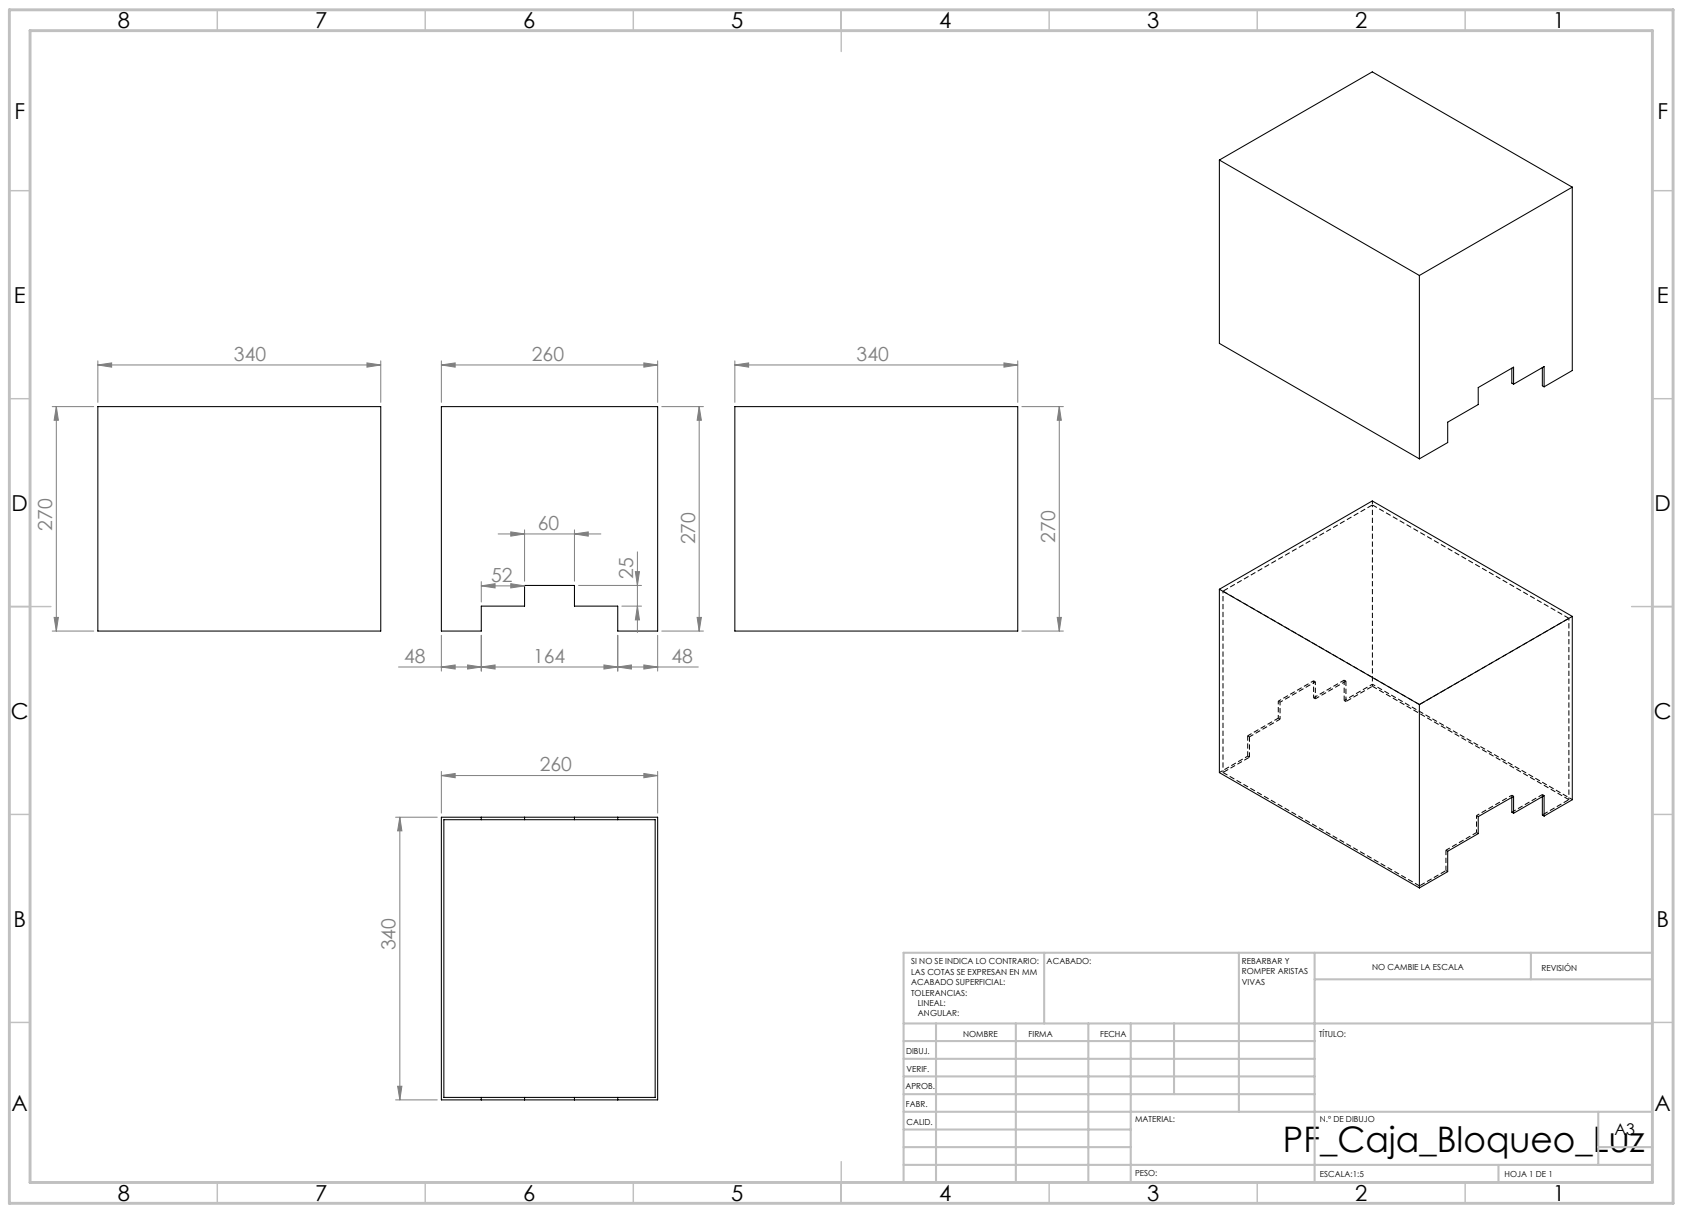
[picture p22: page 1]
ACABADO:; REBARBAR Y; ROMPER ARISTAS; NO CAMBIE LA ESCALA; REVISIÓN; ESCALA:1:5; HOJA 1 DE 1

SI NO SE INDICA LO CONTRARIO:
LAS COTAS SE EXPRESAN EN MM
ACABADO SUPERFICIAL:
TOLERANCIAS:
LINEAL:
ANGULAR:

NOMBRE | FIRMA | FECHA | | | | TÍTULO:

DIBUJ.
VERIF.
APROB.
FABR.
CALID. | | | | MATERIAL: PF_Caja_Bloqueo_Luz | N.º DE DIBUJO | A3

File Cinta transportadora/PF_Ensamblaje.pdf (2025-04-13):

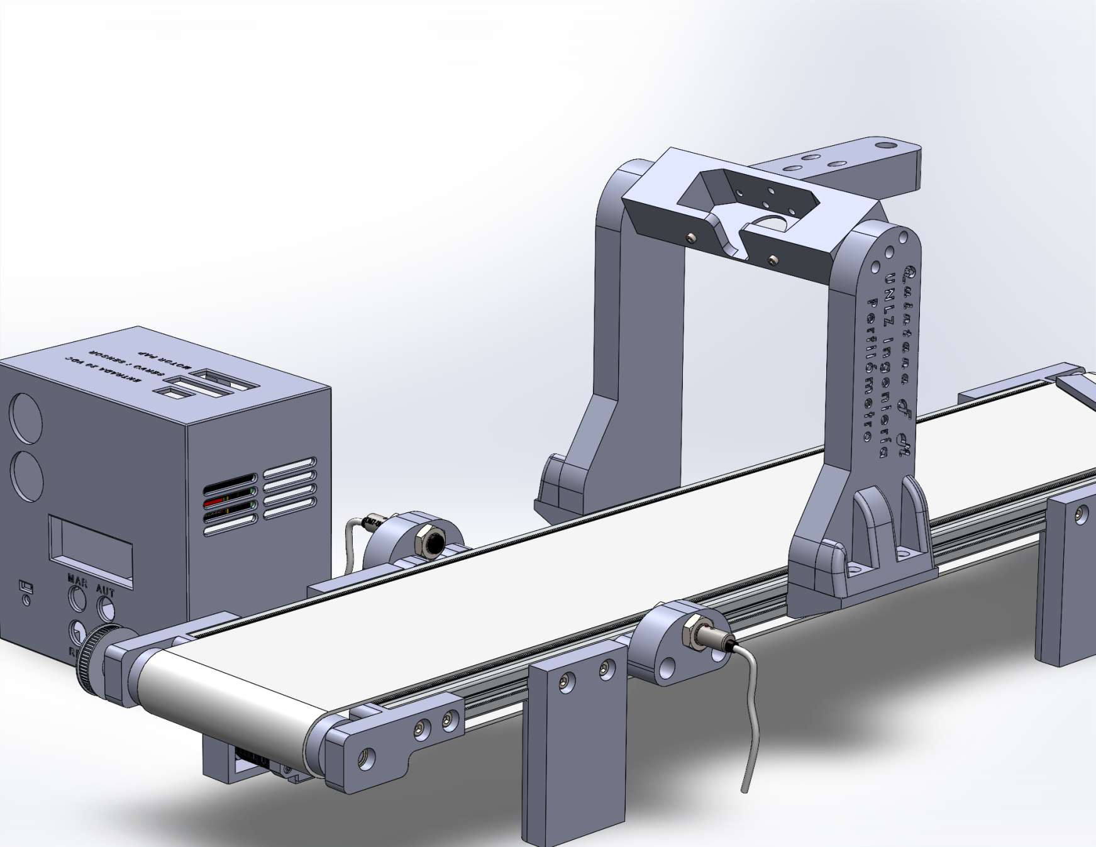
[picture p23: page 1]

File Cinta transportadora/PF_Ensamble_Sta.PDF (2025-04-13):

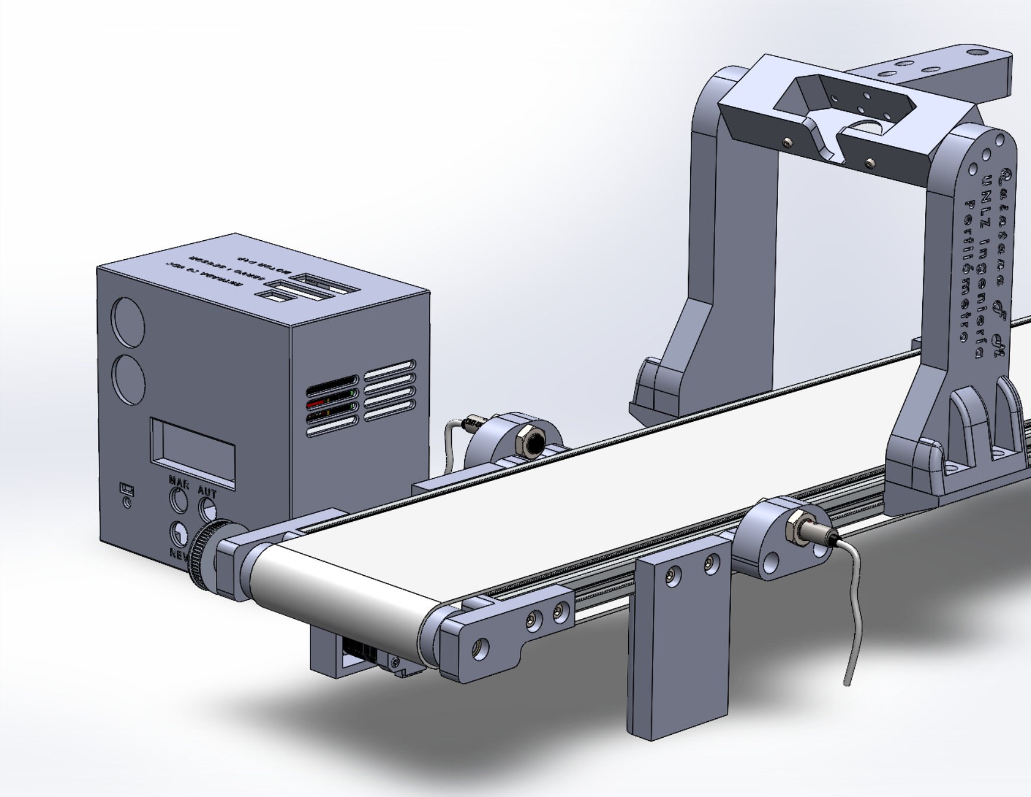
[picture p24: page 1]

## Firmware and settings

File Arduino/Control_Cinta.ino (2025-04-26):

#include <Wire.h>
#include <LiquidCrystal_I2C.h>
#include <Servo.h>

// ----------------- Definición de pines -----------------
#define PULSADOR1 2    // Jog manual: avanzar
#define PULSADOR2 3    // Jog manual: retroceder
#define PULSADOR3 4    // Activa modo AUTOMÁTICO
#define PULSADOR4 5    // SELECT: en manual, alterna entre motor y servo; en automático, cancela
#define SENSOR_PIN 6   // Sensor láser
#define DIR_PIN    7   // Motor PAP direccion
#define PUL_PIN    8   // Motor PAP pulsos
#define SERVO_PIN  9   // Servo MG996R PWM

// ----------------- Configuración del LCD -----------------
LiquidCrystal_I2C lcd(0x27, 16, 2);

// ----------------- Parámetros del motor PAP -----------------
const long stepsPerRev = 3200;          // 3200 micropasos por revolución
const unsigned int steadyDelay = 235;   // µs por mitad del pulso en velocidad estable (~3 s/rev)
volatile long pasos = 0;                // Contador global de micropasos
const float DISTANCIA_MOVIMIENTO = 320.0; // Distancia en mm a recorrer tras detección del sensor

// Relación de transmisión y conversión a pasos
const float relacionTransmision = 60.0 / 20.0; // Relación de poleas 60T/20T = 3
const float diametroRodillo = 32.0 + (1.3 * 2); // Diámetro del rodillo + espesor de la banda
const float circunferenciaRodillo = 3.1416 * diametroRodillo; // Circunferencia total
const long pasosPorMM = (stepsPerRev * relacionTransmision) / circunferenciaRodillo; // Pasos por mm
const long pasosMovimiento = DISTANCIA_MOVIMIENTO * pasosPorMM; // Pasos necesarios para la distancia

// ----------------- Constantes para evaluación -----------------
const float LIMITE_MIN_ANCHO = 16.0; // mm
const float LIMITE_MAX_ANCHO = 20.0; // mm
const float LIMITE_MIN_ALTO = 10.0;  // mm
const float LIMITE_MAX_ALTO = 14.0;  // mm

const int SERVO_POS_OK = 90;         // Posición del servo si es OK
const int SERVO_POS_DE = 140;        // Posición del servo si es DE
const int SERVO_POS_NEUTRO = 90;     // Posición neutral del servo

const float LONGITUD_SALIDA = 450.0; // mm a mover luego de clasificar
const long pasosLargoSalida = LONGITUD_SALIDA * pasosPorMM; // Pasos para los 500 mm

// ----------------- Variables de control -----------------
bool autoModeActive = false;
bool manualDeviceIsPAP = true;          // En modo manual: true = motor PAP; false = servo
Servo servoMotor;
int servoAngle = 90;                    // Ángulo inicial del servo

// ----------------- Variables para mantener últimos datos -----------------
bool datosDisponibles = false;
float ultimoAncho = 0;
float ultimoAlto = 0;
float ultimoLargo = 0;
String ultimoEstado = "";

// ----------------- Función para generar un micropaso -----------------
void stepMotor(unsigned int halfCycleDelay) {
  digitalWrite(PUL_PIN, HIGH);
  delayMicroseconds(halfCycleDelay);
  digitalWrite(PUL_PIN, LOW);
  delayMicroseconds(halfCycleDelay);
}

// ----------------- Función para actualizar el LCD -----------------
void actualizarLCD() {
  lcd.clear();
  lcd.setCursor(0, 0);
  if (autoModeActive) {
    lcd.print("AUTOMATIC MODE");
  } else if (datosDisponibles) {
    lcd.print("W=");
    lcd.print(ultimoAncho, 1);
    lcd.print(" H=");
    lcd.print(ultimoAlto, 1);
    lcd.setCursor(0, 1);
    lcd.print("L=");
    lcd.print(ultimoLargo, 1);
    lcd.print(" S=");
    lcd.print(ultimoEstado);
  } else {
    lcd.print("                ");  // Pantalla vacía
  }
}

// ----------------- Modo AUTOMÁTICO -----------------
void autoMode() {
  autoModeActive = true;
  lcd.clear();
  lcd.setCursor(0, 0);
  lcd.print("AUTOMATIC MODE");
  lcd.setCursor(0, 1);
  lcd.print("Waiting for part");

  digitalWrite(DIR_PIN, HIGH); // Dirección de avance
  long startSteps = pasos;
  bool midiendo = false;

  // Esperar detección de pieza
  while (digitalRead(SENSOR_PIN) == HIGH && digitalRead(PULSADOR4) == LOW) {
    stepMotor(steadyDelay);
    pasos++;
  }

  // Mientras la pieza está bajo el sensor
  while (digitalRead(SENSOR_PIN) == LOW && digitalRead(PULSADOR4) == LOW) {
    if (!midiendo) {
      midiendo = true;
      startSteps = pasos;
    }
    stepMotor(steadyDelay);
    pasos++;
  }

  // Calcular largo (L)
  long detectedSteps = pasos - startSteps;
  float detectedDistance = ((float)detectedSteps / pasosPorMM) + 2.0; // Se suma corrección del sensor

  // Avance de separación para medición
  lcd.clear();
  lcd.setCursor(0, 0);
  lcd.print("AUTOMATIC MODE");
  lcd.setCursor(0, 1);
  lcd.print("Moving to scan");
  for (long i = 0; i < pasosMovimiento && digitalRead(PULSADOR4) == LOW; i++) {
    stepMotor(steadyDelay);
    pasos++;
  }

  // Solicitud de medición a Python
  lcd.clear();
  lcd.setCursor(0, 0);
  lcd.print("AUTOMATIC MODE");
  lcd.setCursor(0, 1);
  lcd.print("Measuring...");
  Serial.print("MEDIR");

  while (!Serial.available()) {
    delay(10);
  }

  String data = Serial.readStringUntil('\n');
  float ancho = 0;
  float alto = 0;

  int separador = data.indexOf(' ');
  if (separador > 0) {
    String parte1 = data.substring(0, separador);
    String parte2 = data.substring(separador + 1);

    ancho = parte1.toFloat();
    alto = parte2.toFloat();
  }

  // Evaluación del perfil
  String estado = "DE";
  if (ancho > LIMITE_MIN_ANCHO && ancho < LIMITE_MAX_ANCHO &&
      alto > LIMITE_MIN_ALTO && alto < LIMITE_MAX_ALTO) {
    estado = "OK";
  }

  // Mostrar resultado inmediatamente
  lcd.clear();
  lcd.setCursor(0, 0);
  lcd.print("W=");
  lcd.print(ancho, 1);
  lcd.print(" H=");
  lcd.print(alto, 1);
  lcd.setCursor(0, 1);
  lcd.print("L=");
  lcd.print(detectedDistance, 1);
  lcd.print(" S=");
  lcd.print(estado);
  delay(1500);

  // Actuar según evaluación
  if (estado == "OK") {
    servoMotor.write(SERVO_POS_OK);
  } else {
    servoMotor.write(SERVO_POS_DE);
  }

  delay(500);

  // Avance hacia salida
  for (long i = 0; i < pasosLargoSalida && digitalRead(PULSADOR4) == LOW; i++) {
    stepMotor(steadyDelay);
  }

  delay(300);
  servoMotor.write(SERVO_POS_NEUTRO);
  delay(500);

  // Guardar datos
  datosDisponibles = true;
  ultimoAncho = ancho;
  ultimoAlto = alto;
  ultimoLargo = detectedDistance;
  ultimoEstado = estado;

  autoModeActive = false;
  actualizarLCD();
}

// ----------------- Modo MANUAL (JOG) para motor PAP -----------------
void manualMotorJog(bool direction) {
  digitalWrite(DIR_PIN, direction ? LOW : HIGH);
  while ((direction ? digitalRead(PULSADOR1) : digitalRead(PULSADOR2)) == HIGH) {
    stepMotor(steadyDelay);
    pasos += (direction ? 1 : -1);
  }
  actualizarLCD();
  lcd.clear();
  lcd.setCursor(0, 0);
  lcd.print("MANUAL MODE");
  lcd.setCursor(0, 1);
  lcd.print("JOG MOTOR");
}

// ----------------- Modo MANUAL (JOG) para el servomotor -----------------
void manualServoJog(bool direction) {
  while ((direction ? digitalRead(PULSADOR1) : digitalRead(PULSADOR2)) == HIGH) {
    servoAngle += direction ? 1 : -1;
    if (servoAngle > 180) servoAngle = 180;
    if (servoAngle < 0) servoAngle = 0;
    servoMotor.write(servoAngle);
    delay(20);
  }
  actualizarLCD();
  lcd.clear();
  lcd.setCursor(0, 0);
  lcd.print("MANUAL MODE");
  lcd.setCursor(0, 1);
  lcd.print("JOG SERVO");
}

// ----------------- Setup y Loop -----------------
void setup() {
  pinMode(DIR_PIN, OUTPUT);
  pinMode(PUL_PIN, OUTPUT);
  pinMode(PULSADOR1, INPUT);
  pinMode(PULSADOR2, INPUT);
  pinMode(PULSADOR3, INPUT);
  pinMode(PULSADOR4, INPUT);
  pinMode(SENSOR_PIN, INPUT);

  lcd.init();
  lcd.backlight();

  // Pantalla de bienvenida fija
  lcd.clear();
  lcd.setCursor(0, 0);
  lcd.print("QUALITY STATION");
  lcd.setCursor(0, 1);
  lcd.print("BY PROFILE SCAN");

  servoMotor.attach(SERVO_PIN);
  servoMotor.write(servoAngle);

  Serial.begin(115200);
  delay(2000);
}

void loop() {
  if (!autoModeActive) {
    if (digitalRead(PULSADOR3) == HIGH) {
      autoMode();
      while (digitalRead(PULSADOR3) == HIGH);
      delay(200);
    }
    if (digitalRead(PULSADOR4) == HIGH) {
      manualDeviceIsPAP = !manualDeviceIsPAP;
      actualizarLCD();
      while (digitalRead(PULSADOR4) == HIGH);
        if (manualDeviceIsPAP == true) {
        lcd.clear();
        lcd.setCursor(0, 0);
        lcd.print("MANUAL MODE");
        lcd.setCursor(0, 1);
        lcd.print("Motor");
      } else {
        lcd.clear();
        lcd.setCursor(0, 0);
        lcd.print("MANUAL MODE");
        lcd.setCursor(0, 1);
        lcd.print("Servo");
      }
      delay(200);
    }
    if (digitalRead(PULSADOR1) == HIGH) {
      if (manualDeviceIsPAP) {
        manualMotorJog(true);
      } else {
        manualServoJog(true);
      }
    }
    if (digitalRead(PULSADOR2) == HIGH) {
      if (manualDeviceIsPAP) {
        manualMotorJog(false);
      } else {
        manualServoJog(false);
      }
    }
  }
}
